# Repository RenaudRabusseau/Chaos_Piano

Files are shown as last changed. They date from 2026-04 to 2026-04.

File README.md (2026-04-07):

# Chaos Piano

An interactive sound and light installation that transforms visitor proximity into coordinated chaos. Built around a decommissioned upright piano for the Fondation du Doute (Blois, France).

As a visitor approaches, the system responds with increasing intensity: vibrating motors excite the piano frame, LED strips strobe with random independent dropouts, a synthesized drone grows louder and more distorted, live microphones capture ambient sound and feed it through reverb and delay, and an ambient track swells through a separate speaker pair.

---

## How It Works

The system is split across two RP2040-Zero microcontrollers connected via I2C. Brain 1 handles the physical world (sensing and actuation), Brain 2 handles audio (synthesis, live processing, and playback). Two separate 12V power supplies isolate the noisy actuation domain from the audio amplifiers.

Four ultrasonic sensors detect visitor proximity and map the closest distance to a single byte (0 = nobody, 255 = very close). This byte drives everything: drone volume and distortion, LED strobe speed, motor outburst frequency, mic processing intensity, and ambient track volume.

### Signal Flow

```
Visitor proximity
    │
    ├──► Brain 1 (RP2040-Zero, dual-core)
    │       Core 0: 4x HC-SR04 sensors → proximity byte → I2C to Brain 2
    │       Core 1: 3x LED strobes with random dropouts
    │                3x motor outbursts (one at a time, spatialized)
    │
    └──► Brain 2 (RP2040-Zero, single-core)
            Drone: sine → distortion → bitcrush → flanger → autopan → I2S DAC
            Mics:  2x MAX9814 → noise gate → reverb → delay → I2S DAC
            Ambient: DFPlayer Mini → separate amp → speakers 3+4
```

### Schematic

[View KiCad schematic (PDF)](KICAD/chaos_piano/chaos_piano.pdf)

---

## Hardware

| Component | Qty | Role |
|---|-----|---|
| RP2040-Zero (Waveshare) | 2 | Brain 1 (controller), Brain 2 (audio) |
| HC-SR04 ultrasonic sensor | 4 | Proximity detection |
| MAX9814 preamp module | 2 | Condenser mic input (40dB, fast AGC) |
| PCM5102 I2S DAC | 1 | Digital audio output |
| PAM8610 amplifier | 2 | Speaker drivers (separate PSU from actuation) |
| Speakers (4 ohm 10W) | 4 | 2 for live audio, 2 for ambient track |
| DFPlayer Mini | 1 | Ambient MP3 playback |
| IRLZ44N N-MOSFET | 6 | 12V switching (3 motors, 3 LED strips) |
| Vibrating motor | 3 | Tactile/acoustic excitation |
| 12V RGB LED strip | 3 | Visual feedback (white strobe) |
| 12V PSU | 2 | #1 brains + actuation, #2 audio amplifiers |
| 5V step-down converter | 1 | Powers sensors and DFPlayer from PSU #1 |

### Custom Boards

Three perfboards built by hand with screw terminals for field serviceability:

**MOSFET board:** 6x IRLZ44N with 10k pull-downs and flyback diodes, 12V/GND rails.
**Voltage divider board:** 4x dividers (1k/2k) converting 5V HC-SR04 echo signals to 3.3V.
**I2C board:** 2x 4.7k pull-ups, 4 screw terminals (SDA, SCL, 3.3V, GND).

### Power Architecture

Two separate 12V supplies eliminate ground-coupled PWM noise from the audio path:

- **PSU #1:** MOSFET board, 5V step-down (sensors, DFPlayer), brains (via USB for desk prototype)
- **PSU #2:** Both PAM8610 amplifiers only

---

## Audio DSP Chain

Brain 2 runs a real-time audio engine at 44100Hz, synchronized to DMA-based ADC sampling.

**Drone path (synthesized):** Phase-accumulator sine oscillator (440Hz) through proximity-scaled distortion (up to 8x gain, hard clip), bitcrusher (up to 12 bits removed), flanger (1024-sample buffer, triangle LFO), proximity volume, and stereo autopanner.

**Mic path (live input):** Two MAX9814 condenser mics sampled via round-robin ADC at 22050Hz each, mono downmixed, through asymmetric noise gate, Schroeder reverb (4 comb filters), and 600ms delay with feedback.

**Ambient path (separate analog):** DFPlayer Mini decodes MP3 from SD card, analog output to PAM8610 #2 through its own DAC. Volume controlled by Brain 2 via 9600 baud UART.

---

## Actuation Behavior

**LEDs:** Unified strobe rate scales with proximity. Each strip independently drops out (goes dark) for random durations. Dropout probability increases with proximity, creating visual chaos.

**Motors:** Gentle baseline hum scales with proximity. Individual motors fire random outbursts (one at a time, never simultaneous) with randomly chosen sharp or faded attacks. Outburst frequency, intensity, and duration increase with proximity, spatializing tactile chaos across three positions.

---

## Build and Upload

Requires [PlatformIO](https://platformio.org/).

```bash
# Build both brains
pio run

# Upload Brain 1 (blue heartbeat LED)
pio run -e brain1_controller -t upload

# Upload Brain 2 (green triple-flash LED)
pio run -e brain2_audio -t upload

# Monitor Brain 1
pio device monitor -p /dev/serial/by-id/usb-Waveshare_RP2040_Zero_E66428C51F4BB630-if00 -b 115200

# Monitor Brain 2
pio device monitor -p /dev/serial/by-id/usb-Waveshare_RP2040_Zero_E66428C51F63B530-if00 -b 115200
```

---

## Repository Structure

```
Chaos_Piano/
├── README.md                        # This file
├── ARCHITECTURE.md                  # Complete technical reference
├── platformio.ini                   # Build config: two environments
├── KICAD/
│   └── chaos_piano/
│       ├── chaos_piano.kicad_sch    # Schematic
│       ├── chaos_piano.kicad_pcb    # PCB layout
│       └── chaos_piano.pdf          # Schematic export
├── lib/
│   └── shared_protocol/
│       ├── chaos_protocol.h         # Pin assignments, I2C protocol, message format
│       └── library.json             # PlatformIO library metadata
└── src/
    ├── brain1_controller/
    │   └── main.cpp                 # Core 0: sensors + I2C. Core 1: chaotic LEDs + motors.
    └── brain2_audio/
        └── main.cpp                 # Audio engine: drone DSP + dual mic + DFPlayer
```

See [ARCHITECTURE.md](ARCHITECTURE.md) for the complete technical reference including pin maps, wiring diagrams, communication protocol, and all tuning parameters.

---

## Academic Context

Developed as a portfolio project for a BTS CIEL (Cybersecurity, IT and Electronics) program. Demonstrates practical competency across embedded systems, real-time signal processing, and human-machine interaction:

- Dual-microcontroller architecture with I2C inter-processor communication
- Real-time DSP on a 133MHz ARM Cortex-M0+ (no FPU, no RTOS)
- DMA-driven ADC for jitter-free audio sampling
- Power domain isolation for EMI management
- Custom perfboard design and hand assembly
- Proximity-driven state machine with randomized actuation behavior

---

## Author

**Renaud Rabusseau** - Electronics engineering student, former technical translator and conference interpreter. This project bridges 15 years of professional audio experience with embedded systems engineering.

---

## License

This project is open source. See individual files for details.

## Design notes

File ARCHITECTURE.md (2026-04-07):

# Chaos Piano — Architecture Reference

**Version:** April 2026 desk prototype (final working build)
**Target:** La Fondation du Doute, Blois, France — May 2026
**Author:** Renaud

---

## Concept

Interactive sound installation where human proximity controls audio effects,
lighting, and physical actuators. The closer a visitor gets, the more chaotic
the piano becomes: the drone grows louder and more distorted, LED strips strobe
faster with random independent dropouts, motors fire random independent
outbursts, and the ambient track swells.

---

## System Overview

```
  ┌──────────────────────┐          ┌──────────────────────┐
  │    12V PSU #1         │          │    12V PSU #2         │
  │  (brains + actuation) │          │  (audio amplifiers)   │
  └──┬────────┬───────────┘          └──┬────────┬──────────┘
     │        │                         │        │
  ┌──▼──┐  ┌──▼──┐                   ┌──▼──┐  ┌──▼──┐
  │Motor│  │ LED │                   │PAM  │  │PAM  │
  │MOSFET│ │MOSFET│                  │8610 │  │8610 │
  │board │ │board │                  │ #1  │  │ #2  │
  └──▲──┘  └──▲──┘                   └──▲──┘  └──▲──┘
     │        │                         │        │
     │        │     ┌───────────────────┘        │
     │        │     │    ┌──────────────────────-┘
     │        │     │    │
  ┌──┴────────┴─────┴────┴─────────────────────────────────┐
  │                                                        │
  │  ┌──────────────┐    I2C     ┌──────────────────────┐  │
  │  │   BRAIN 1    │◄──────────►│      BRAIN 2         │  │
  │  │  Controller  │  (4 bytes  │    Audio Engine      │  │
  │  │  RP2040-Zero │  @ 20Hz)   │    RP2040-Zero       │  │
  │  └──────┬───────┘            └──┬────┬────┬─────────┘  │
  │         │                       │    │    │            │
  │    ┌────▼────┐             ┌────▼┐ ┌─▼──┐ ┌▼────────┐  │
  │    │ HC-SR04 │             │MAX  │ │I2S │ │DFPlayer │  │
  │    │  ×4     │             │9814 │ │DAC │ │Mini     │  │
  │    └─────────┘             │ ×2  │ │PCM │ │(ambient)│  │
  │                            └─────┘ │5102│ └─────────┘  │
  │                                    └────┘              │
  └────────────────────────────────────────────────────────┘
```

---

## Power Architecture

The system uses two separate 12V power supplies to eliminate ground-coupled
PWM switching noise from the audio path. This was the key fix for audible
LED/motor buzz in the speakers.

| PSU | Voltage | Min Current | Powers |
|-----|---|---|---|
| PSU #1 | 12V | 2A+ | MOSFET board (motors, LEDs), 5V step-down (sensors, DFPlayer), brains (via USB) |
| PSU #2 | 12V | 2A+ | PAM8610 #1 (live audio), PAM8610 #2 (ambient audio) |

The two PSUs share no ground connection. The brains are powered via USB
from a computer (desk prototype) or from PSU #1's 5V step-down (exhibit mode).
The 5V step-down converts PSU #1's 12V to 5V for the HC-SR04 sensors and
the DFPlayer Mini.

---

## Components

| Component | Qty | Role | Voltage | Notes |
|---|-----|---|---|---|
| RP2040-Zero (Waveshare) | 2 | Brain 1 (controller), Brain 2 (audio) | 3.3V (USB-C 5V) | Orange tape = Brain 1, new board = Brain 2 |
| HC-SR04 ultrasonic sensor | 4 | Distance detection | 5V | ECHO needs voltage divider (1kΩ + 2kΩ) |
| MAX9814 preamp module | 2 | Condenser mic input | 3.3V | GAIN → 3.3V = 40dB, AR → 3.3V = fast release |
| PCM5102 I2S DAC | 1 | Digital-to-analog audio output | 3.3V | SCK pin → GND (internal clock mode) |
| PAM8610 amplifier | 2 | Speaker driver | 12V (PSU #2) | #1 for live audio, #2 for DFPlayer ambient |
| Speakers (4Ω 10W) | 4 | Sound output | — | 2 per PAM8610 (stereo) |
| DFPlayer Mini | 1 | Ambient track playback | 5V | 4GB MicroSD with 001.mp3 in root |
| IRLZ44N N-MOSFET (TO-220) | 6 | 12V switching for motors/LEDs | — | Logic-level: fully on at 3.3V gate |
| Vibrating motor | 3 | Tactile feedback | 12V | Flyback diode (1N4007) required |
| 12V LED strip (RGB) | 3 | Visual feedback (white strobe) | 12V | All 3 color wires joined → single MOSFET |
| 12V PSU | 2 | Power | 12V | #1 for brains+actuation, #2 for amps |
| 5V step-down converter | 1 | 12V → 5V for sensors + DFPlayer | 5V | Connected to PSU #1 |
| 1kΩ resistor | 5 | 4× voltage divider top + 1× DFPlayer TX | — | |
| 2kΩ resistor | 4 | HC-SR04 voltage divider (bottom) | — | One per echo line |
| 4.7kΩ resistor | 2 | I2C pull-ups (SDA + SCL) | — | To 3.3V, mounted on I2C board |
| 10kΩ resistor | 6 | MOSFET gate pull-downs | — | One per MOSFET: gate → source |
| 1N4007 diode | 3 | Motor flyback protection | — | Cathode (stripe) → motor +, anode → motor − |
| 4GB MicroSD card | 1 | DFPlayer audio storage | — | FAT32, file: /001.mp3 |

---

## Custom Boards

### MOSFET Board
Perfboard with 6× IRLZ44N MOSFETs (3 for LEDs, 3 for motors), 6× 10kΩ
gate pull-down resistors, 3× 1N4007 flyback diodes (motor MOSFETs only),
12V and GND power rails. Screw terminals for load connections.

### Voltage Divider Board
Perfboard with 4× voltage dividers (1kΩ top + 2kΩ bottom) for the HC-SR04
echo lines. Converts 5V echo signals to ~3.3V safe for RP2040 GPIO inputs.
DuPont connectors on the Brain 1 side, open leads to Wago connectors on
the sensor side.

### I2C Board
Small perfboard with 4 screw terminals (SDA, SCL, 3.3V, GND) and 2× 4.7kΩ
pull-up resistors (SDA→3.3V, SCL→3.3V). Both brains connect their I2C lines
here. 3.3V sourced from one brain's 3V3 pin.

---

## Boards

### Brain 1 — Physical Controller

- **Board:** RP2040-Zero (Waveshare), orange tape
- **Serial:** `E66428C51F4BB630`
- **USB port:** `/dev/serial/by-id/usb-Waveshare_RP2040_Zero_E66428C51F4BB630-if00`
- **PlatformIO env:** `brain1_controller`
- **NeoPixel:** Blue heartbeat (1s on, 1s off)
- **Role:** Reads 4 ultrasonic sensors, computes proximity, sends I2C to Brain 2, drives chaotic motor outbursts and LED strobes with random dropouts
- **Architecture:** Dual-core. Core 0 = sensors + I2C. Core 1 = LED strobe + motor chaos.

### Brain 2 — Audio Engine

- **Board:** RP2040-Zero (Waveshare), no tape
- **Serial:** `E66428C51F63B530`
- **USB port:** `/dev/serial/by-id/usb-Waveshare_RP2040_Zero_E66428C51F63B530-if00`
- **PlatformIO env:** `brain2_audio`
- **NeoPixel:** Green triple-flash (3 blinks, 1.5s cycle)
- **Role:** Receives proximity via I2C, generates drone with DSP effects, processes dual live mics, controls DFPlayer ambient track
- **Architecture:** Single-core. Audio processing synchronized to ADCInput DMA at 44100Hz.

---

## Pin Map

### Brain 1

| GPIO | Function | Direction | Notes |
|---|---|---|---|
| 0 | LED strip 0 MOSFET gate | OUT | 10kΩ pull-down to GND |
| 1 | LED strip 1 MOSFET gate | OUT | 10kΩ pull-down to GND |
| 2 | LED strip 2 MOSFET gate | OUT | 10kΩ pull-down to GND |
| 3 | *free* | — | Available on edge header |
| 4 | I2C SDA | I/O | 4.7kΩ pull-up to 3.3V (on I2C board) |
| 5 | I2C SCL | I/O | 4.7kΩ pull-up to 3.3V (on I2C board) |
| 6 | Ultrasonic TRIGGER (shared) | OUT | All 4 sensors share this pin |
| 7 | Ultrasonic ECHO 0 | IN | 1kΩ + 2kΩ voltage divider from 5V |
| 8 | Ultrasonic ECHO 1 | IN | 1kΩ + 2kΩ voltage divider from 5V |
| 9 | Ultrasonic ECHO 2 | IN | 1kΩ + 2kΩ voltage divider from 5V |
| 10 | Ultrasonic ECHO 3 | IN | 1kΩ + 2kΩ voltage divider from 5V |
| 11 | Motor 0 MOSFET gate | OUT | 10kΩ pull-down, flyback diode on motor |
| 12 | Motor 1 MOSFET gate | OUT | 10kΩ pull-down, flyback diode on motor |
| 13 | Motor 2 MOSFET gate | OUT | 10kΩ pull-down, flyback diode on motor |
| 14 | *free* | — | Available on edge header |
| 15 | *free* | — | Available on edge header |
| 16 | Onboard NeoPixel (WS2812) | OUT | Hardwired — cannot be reassigned |

### Brain 2

| GPIO | Function | Direction | Notes |
|---|---|---|---|
| 0 | DFPlayer TX | OUT | 1kΩ resistor to DFPlayer RX |
| 1 | DFPlayer RX | IN | Direct connection |
| 2 | *free* | — | |
| 3 | *free* | — | |
| 4 | I2C SDA | I/O | 4.7kΩ pull-up to 3.3V (on I2C board) |
| 5 | I2C SCL | I/O | 4.7kΩ pull-up to 3.3V (on I2C board) |
| 6 | I2S BCK (bit clock) | OUT | To PCM5102 BCK |
| 7 | I2S LRCK (word select) | OUT | To PCM5102 LCK (auto = BCK+1) |
| 8 | I2S DOUT (data) | OUT | To PCM5102 DIN |
| 9-15 | *free* | — | |
| 16 | Onboard NeoPixel (WS2812) | OUT | Hardwired |
| 26 | MAX9814 mic 0 (ADC0) | IN | Analog input |
| 27 | MAX9814 mic 1 (ADC1) | IN | Analog input |
| 28 | *free* (ADC2) | IN | |

---

## Wiring Reference

### I2C Bus (via I2C board)

```
Brain 1 GPIO4 (SDA) ──┐
                       ├── I2C Board SDA terminal ── 4.7kΩ ── 3.3V
Brain 2 GPIO4 (SDA) ──┘

Brain 1 GPIO5 (SCL) ──┐
                       ├── I2C Board SCL terminal ── 4.7kΩ ── 3.3V
Brain 2 GPIO5 (SCL) ──┘

Either brain GND ──── I2C Board GND terminal
Either brain 3V3 ──── I2C Board 3.3V terminal
```

### HC-SR04 Ultrasonic Sensor (×4, example for sensor 0)

```
5V (step-down) ──── HC-SR04 VCC
GND            ──── HC-SR04 GND
Brain 1 GPIO6  ──── HC-SR04 TRIG  (shared by all 4 sensors via Wago)

HC-SR04 ECHO ──── 1kΩ ──┬──── Brain 1 GPIO7
                         │
                        2kΩ
                         │
                        GND
```
The 1kΩ + 2kΩ voltage divider converts the HC-SR04's 5V echo signal to
~3.3V for the RP2040's GPIO input. Without this, the 5V would damage the chip.

### Motor Circuit (×3, example for motor 0)

```
12V PSU #1 (+) ──── Motor (+)
                    Motor (−) ──── IRLZ44N Drain (center pin)
                                    IRLZ44N Source (right pin) ──── GND
                                    IRLZ44N Gate (left pin) ──── Brain 1 GPIO11
                                             │
                                            10kΩ
                                             │
                                            GND

Flyback diode across motor:
  Cathode (stripe) → Motor (+)
  Anode → Motor (−)
```

### LED Strip Circuit (×3, example for strip 0)

```
12V PSU #1 (+) ──── LED strip (+12V)
LED strip R (−) ─┐
LED strip G (−) ──┤──── IRLZ44N Drain (center pin)
LED strip B (−) ─┘      IRLZ44N Source (right pin) ──── GND
                          IRLZ44N Gate (left pin) ──── Brain 1 GPIO0
                                   │
                                  10kΩ
                                   │
                                  GND
```
All 3 color wires joined together = white when ON. Single MOSFET controls brightness.

### PCM5102 DAC

```
Brain 2 GPIO6 ──── BCK
Brain 2 GPIO7 ──── LCK
Brain 2 GPIO8 ──── DIN
3.3V          ──── VIN
GND           ──── GND
GND           ──── SCK  (ties internal clock mode)

PCM5102 3.5mm out ──── PAM8610 #1 audio input
```

### DFPlayer Mini

```
Brain 2 GPIO0 ──── 1kΩ ──── DFPlayer RX
Brain 2 GPIO1 ──────────── DFPlayer TX
5V (step-down) ─────────── DFPlayer VCC
GND           ──────────── DFPlayer GND
DFPlayer DAC_L ──── PAM8610 #2 Left input
DFPlayer DAC_R ──── PAM8610 #2 Right input
```

### MAX9814 Microphone (×2)

```
Mic 0:
  3.3V ──── MAX9814 VDD
  GND  ──── MAX9814 GND
  3.3V ──── MAX9814 GAIN  (40dB gain setting)
  3.3V ──── MAX9814 AR    (fastest AGC release = 1:500)
  MAX9814 OUT ──── Brain 2 GPIO26 (ADC0)

Mic 1:
  3.3V ──── MAX9814 VDD
  GND  ──── MAX9814 GND
  3.3V ──── MAX9814 GAIN  (40dB gain setting)
  3.3V ──── MAX9814 AR    (fastest AGC release = 1:500)
  MAX9814 OUT ──── Brain 2 GPIO27 (ADC1)
```

### PAM8610 Amplifiers

```
PAM8610 #1 (live audio):
  12V PSU #2 ──── Power in
  GND PSU #2 ──── GND
  PCM5102 3.5mm ──── Audio input
  Speakers 1+2 ──── Output L/R

PAM8610 #2 (ambient):
  12V PSU #2 ──── Power in
  GND PSU #2 ──── GND
  DFPlayer DAC_L/R ──── Audio input L/R
  Speakers 3+4 ──── Output L/R
```

---

## Communication Protocol

### I2C (Brain 1 → Brain 2)

- **Address:** 0x42
- **Speed:** 100kHz
- **Rate:** 20Hz (every 50ms)
- **Message:** 4 bytes, packed struct:

| Byte | Field | Description |
|---|---|---|
| 0 | header | Magic byte 0xC0 |
| 1 | proximity | 0=nobody, 255=very close |
| 2 | sensor_count | Valid sensors this sweep (0-4) |
| 3 | checksum | XOR of bytes 0-2 |

### DFPlayer Serial (Brain 2 → DFPlayer)

- **UART:** Serial1 at 9600 baud
- **Protocol:** 10-byte frames (0x7E start, 0xEF end, checksum)
- **Commands used:** 0x06 (set volume), 0x08 (loop track)
- **Rate limit:** Max 1 command per 200ms

---

## Audio Signal Chain

```
DRONE PATH:
  fastSine(440Hz)
    → >>DRONE_PRE_SHIFT (headroom)
    → Distortion (gain 1x-8x, hard clip)
    → Bitcrusher (0-12 bits removed)
    → Flanger (1024-sample buffer, triangle LFO)
    → Proximity Volume (DRONE_VOLUME_MIN → DRONE_VOLUME_MAX)
    → Autopan (triangle LFO, speed+depth scale with proximity)
    → stereo L/R

MIC PATH (dual mic, interleaved ADC):
  MAX9814 ×2 (40dB, ADC via DMA at 44100Hz, round-robin → 22050Hz each)
    → DC bias removal (subtract MIC_BIAS)
    → Mono downmix (average of both mics)
    → Noise Gate (asymmetric envelope, threshold-based mute)
    → MIC_VOLUME scaling
    → Reverb (4 comb filters, Schroeder design)
    → Delay (circular buffer, 600ms, feedback)
    → mono (centered in both channels)

FINAL MIX:
  droneLeft + mic → clip → I2S left
  droneRight + mic → clip → I2S right
    → PCM5102 DAC → 3.5mm → PAM8610 #1 (PSU #2) → Speakers 1+2

DFPLAYER PATH (separate analog):
  SD card → DFPlayer decoder → DAC_L/DAC_R → PAM8610 #2 (PSU #2) → Speakers 3+4
  Volume controlled by Brain 2 UART commands (proximity-scaled)
```

---

## Actuation Behavior

### LED Strips (Core 1, Brain 1)

**Idle (prox < LED_PROX_THRESHOLD):** All three strips pulse together in a
slow dim/bright cycle, making the installation look alive even when nobody
is nearby.

**Active (prox >= threshold):** All three strips strobe at the same rate,
which increases with proximity. On top of the shared strobe, each strip
independently and randomly "drops out" (goes dark) for a short random
duration. Dropout probability and duration scale with proximity: at low
proximity the strobe is uniform, at high proximity the three strips blink
in and out chaotically.

### Motors (Core 1, Brain 1)

**Idle (prox = 0):** All motors off.

**Active (prox > 0):** All three motors run at a gentle baseline PWM that
scales with proximity. On top of this baseline, individual motors randomly
fire outbursts: short bursts to higher intensity, one motor at a time (never
simultaneous). Each burst randomly uses either a sharp snap or a smooth fade
for its attack. The return to baseline always fades smoothly. Outburst
frequency, intensity, and duration all increase with proximity, creating
spatialized tactile chaos across the three motor positions.

---

## Build Commands

```bash
# Build both brains
pio run

# Upload Brain 1 only
pio run -e brain1_controller -t upload

# Upload Brain 2 only
pio run -e brain2_audio -t upload

# Monitor Brain 1 (blue heartbeat)
pio device monitor -p /dev/serial/by-id/usb-Waveshare_RP2040_Zero_E66428C51F4BB630-if00 -b 115200

# Monitor Brain 2 (green triple-flash)
pio device monitor -p /dev/serial/by-id/usb-Waveshare_RP2040_Zero_E66428C51F63B530-if00 -b 115200

# Monitor both simultaneously (interleaved output)
pio device monitor -p /dev/serial/by-id/usb-Waveshare_RP2040_Zero_E66428C51F4BB630-if00 -b 115200 &
pio device monitor -p /dev/serial/by-id/usb-Waveshare_RP2040_Zero_E66428C51F63B530-if00 -b 115200
```

---

## Tuning Parameters Quick Reference

### Brain 1 (src/brain1_controller/main.cpp)

| Parameter | Default | Range | Effect |
|---|---|---|---|
| DETECT_MIN_CM | 1 | 1-50 | Closest detection distance |
| DETECT_MAX_CM | 75 | 50-400 | Farthest detection distance |
| MOTOR_BASELINE_MIN | 0 | 0-50 | Motor baseline PWM at prox=0 |
| MOTOR_BASELINE_MAX | 40 | 10-100 | Motor baseline PWM at max proximity |
| MOTOR_BURST_MIN | 80 | 40-150 | Minimum burst intensity |
| MOTOR_BURST_MAX | 180 | 100-255 | Maximum burst intensity |
| MOTOR_BURST_DUR_MIN | 50 | 20-200 | Shortest burst (ms) |
| MOTOR_BURST_DUR_MAX | 400 | 100-1000 | Longest burst (ms) |
| MOTOR_PAUSE_MIN | 200 | 50-500 | Shortest gap between bursts (ms) |
| MOTOR_PAUSE_MAX | 2000 | 500-5000 | Longest gap between bursts (ms) |
| MOTOR_FADE_SPEED | 8 | 1-32 | PWM change per loop iteration (higher=faster) |
| LED_IDLE_BRIGHT | 15 | 0-255 | Idle blink ON brightness |
| LED_IDLE_DIM | 5 | 0-255 | Idle blink OFF brightness |
| LED_IDLE_PERIOD_MS | 1000 | 200-5000 | Idle blink half-period (ms) |
| LED_STROBE_BRIGHT_MIN | 30 | 0-255 | Active strobe dim brightness |
| LED_STROBE_BRIGHT_MAX | 255 | 0-255 | Active strobe full brightness |
| LED_STROBE_SLOW_US | 500000 | 100000-2000000 | Slowest strobe (us) |
| LED_STROBE_FAST_US | 2000 | 500-50000 | Fastest strobe (us) |
| LED_PROX_THRESHOLD | 5 | 1-50 | Proximity to exit idle mode |
| LED_DROPOUT_DUR_MIN | 30 | 10-200 | Shortest LED dropout (ms) |
| LED_DROPOUT_DUR_MAX | 300 | 50-1000 | Longest LED dropout (ms) |
| LED_DROPOUT_CHANCE_MIN | 0 | 0-20 | Dropout probability at low prox (0-255 scale) |
| LED_DROPOUT_CHANCE_MAX | 40 | 10-100 | Dropout probability at max prox (0-255 scale) |
| SENSOR_ZERO_MAX | 10 | 3-30 | Consecutive 0s before release |

### Brain 2 (src/brain2_audio/main.cpp)

| Parameter | Default | Range | Effect |
|---|---|---|---|
| MIC_BIAS | 1540 | 1400-1700 | MAX9814 DC offset (calibrate!) |
| MIC_VOLUME | 255 | 0-255 | Mic loudness (128=unity, 255=2x boost) |
| GATE_THRESHOLD | 200 | 50-5000 | Noise gate sensitivity |
| GATE_ATTACK | 0.5 | 0.01-1.0 | Gate open speed |
| GATE_RELEASE | 0.1 | 0.001-0.5 | Gate close speed |
| REVERB_DECAY | 215 | 150-225 | Reverb tail length |
| REVERB_WET | 200 | 0-255 | Reverb wet/dry mix |
| DELAY_TIME_MS | 600 | 100-800 | Echo time in ms |
| DELAY_FEEDBACK | 100 | 0-200 | Echo repeats (200+=danger) |
| DELAY_MIX | 140 | 0-255 | Echo volume |
| DRONE_FREQ_HZ | 440 | 50-2000 | Drone pitch in Hz |
| DRONE_PRE_SHIFT | 2 | 1-4 | Headroom (higher=quieter input to FX) |
| DRONE_VOLUME_MIN | 120 | 0-255 | Drone volume at idle |
| DRONE_VOLUME_MAX | 255 | 0-255 | Drone volume at closest |
| DIST_GAIN_MULTIPLIER | 7 | 1-15 | Distortion max gain factor |
| BITCRUSH_MAX_BITS | 12 | 1-14 | Max bit reduction |
| FLANGER_LFO_SPEED | 97391 | 10000-500000 | Flanger sweep rate |
| PAN_SPEED_MIN | 15000 | 1000-100000 | Slowest autopan |
| PAN_SPEED_MAX | 300000 | 100000-1000000 | Fastest autopan |
| PAN_DEPTH_MIN | 0 | 0-128 | Pan width when idle |
| PAN_DEPTH_MAX | 200 | 0-255 | Pan width at closest |
| DFPLAYER_VOL_MIN | 15 | 0-30 | Ambient volume idle |
| DFPLAYER_VOL_MAX | 30 | 0-30 | Ambient volume closest |
| DFPLAYER_TRACK | 1 | 1-99 | Track number to loop |
| GLITCH_CHANCE_MIN | 0 | 0-50 | Glitch probability idle |
| GLITCH_CHANCE_MAX | 0 | 0-255 | Glitch probability closest (0=off) |
| GLITCH_MIN_LENGTH | 2000 | 441-22050 | Shortest glitch (samples) |
| GLITCH_MAX_LENGTH | 10000 | 2000-44100 | Longest glitch (samples) |
| GLITCH_FADE_SPEED | 4 | 1-16 | Glitch fade smoothness |

---

## Project Structure

```
chaos-piano/
├── platformio.ini                   # Build config: two environments
├── lib/
│   └── shared_protocol/
│       ├── chaos_protocol.h         # SINGLE SOURCE OF TRUTH: pins, I2C, message format
│       └── library.json             # PlatformIO library metadata
├── src/
│   ├── brain1_controller/
│   │   └── main.cpp                 # Core 0: sensors + I2C. Core 1: chaotic LEDs + motors.
│   └── brain2_audio/
│       └── main.cpp                 # Audio engine: drone DSP + dual mic + DFPlayer
└── ARCHITECTURE.md                  # This file
```

---

## Resolved Issues

- **EMI from MOSFET PWM switching:** 12V PWM switching on the MOSFET board
  coupled ground noise into both audio amplifiers (audible as a buzz/whine
  synchronized with LED blink rate). **Fixed** by using a separate 12V PSU
  for the two PAM8610 amplifiers, completely isolating the audio ground
  from the actuation ground.

- **Floating ADC inputs:** Before the MAX9814 mics were connected, the ADC
  inputs on GPIO26/27 floated at ~2950, causing the noise gate to stay
  permanently open. **Fixed** by connecting both mics (the MAX9814 output
  provides a stable DC bias around 1540).

- **Dead PCM5102 module:** During a rebuild, the PCM5102 DAC's LCK input
  was damaged (pulling the line from 1.6V to 0.5V). **Fixed** by replacing
  the module. Lesson: handle these boards carefully and avoid shorts during
  rewiring.

## Known Limitations

- **Feedback loop:** MAX9814 AGC boosts quiet feedback from speakers. Managed
  by tuning GATE_THRESHOLD, MIC_VOLUME, REVERB_WET, and DELAY_FEEDBACK.
  Physical separation of mic and speakers remains important for the final build.

- **DFPlayer glitch sync:** DFPlayer mute commands have ~30-50ms latency
  (serial processing). Glitch cuts won't be perfectly synchronized with live
  audio. (Glitch system currently disabled: GLITCH_CHANCE_MAX = 0.)

- **Standalone boot:** Uses `delay(2000)` instead of `while(!Serial)`. Works
  for exhibit mode (no computer needed) but serial output may be missed if
  monitor isn't open within 2 seconds of boot.

- **Dual mic sample rate:** With two mics sharing one ADC via round-robin,
  each mic is sampled at 22050Hz (half the 44100Hz ADC clock). Adequate for
  voice and claps but limits high-frequency capture above ~10kHz.

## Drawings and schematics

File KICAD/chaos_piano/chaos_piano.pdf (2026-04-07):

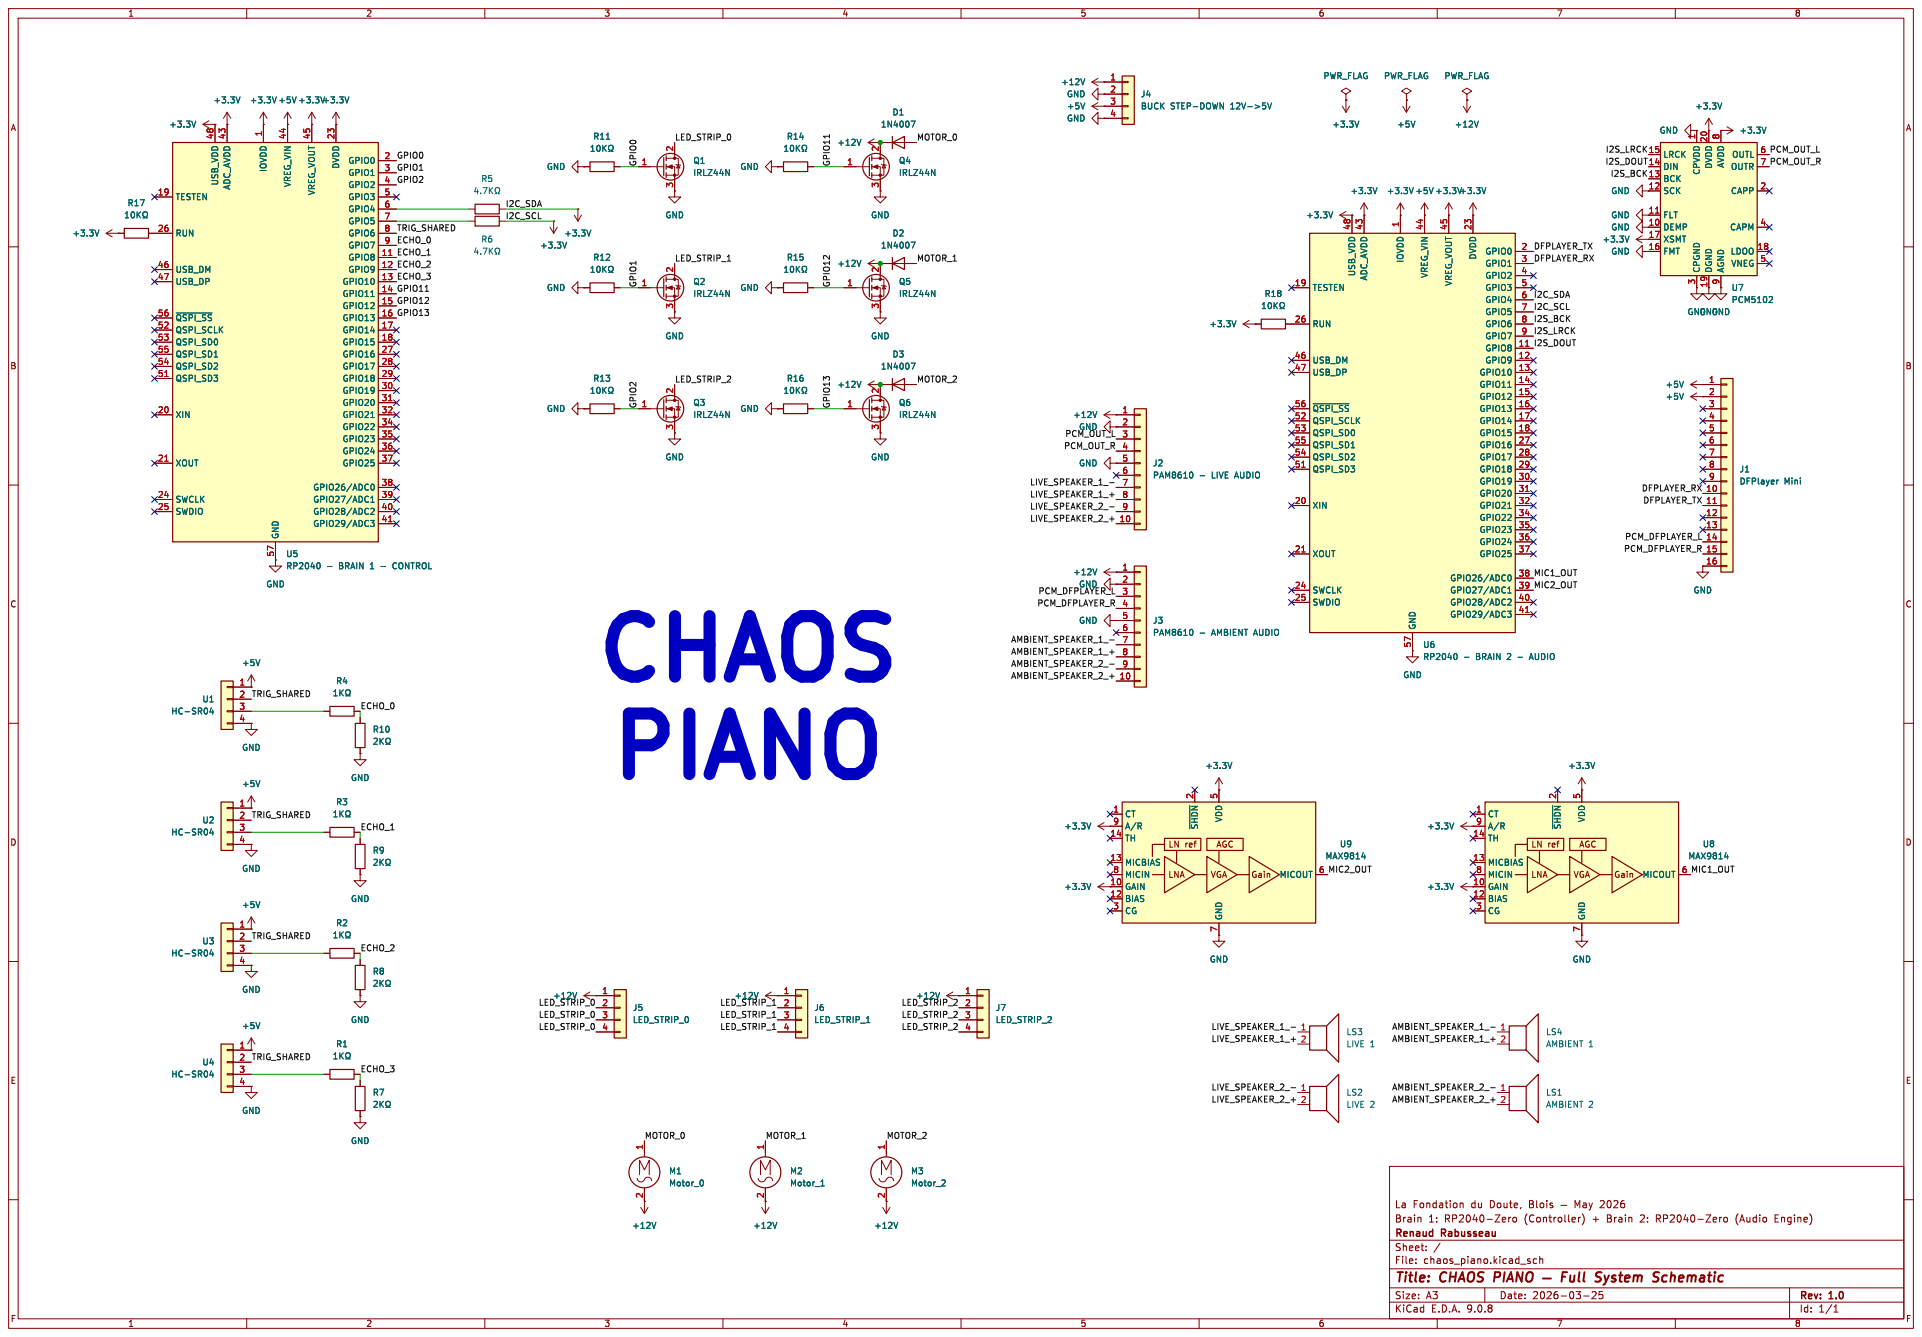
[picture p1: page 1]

1 GND 57 VREG_VIN 44 VREG_VOUT 45 DVDD 23 GPIO0 2 GPIO1 3 GPIO2 4 GPIO3 5 GPIO4 6 GPIO5 7 GPIO6 8 GPIO7 9 GPIO8 11 GPIO9 12 GPIO10 13 GPIO11 14 GPIO12 15 GPIO13 16 GPIO14 17 GPIO15 18 GPIO16 27 GPIO17 28 GPIO18 29 GPIO19 30 GPIO20 31 GPIO21 32 GPIO22 34 GPIO23 35 GPIO24 36 GPIO25 37 GPIO26/ADC0 38 GPIO27/ADC1 39 GPIO28/ADC2 40 GPIO29/ADC3 41 U5 RP2040 - BRAIN 1 - CONTROL

1 GND 57 VREG_VIN 44 VREG_VOUT 45 DVDD 23 GPIO0 2 GPIO1 3 GPIO2 4 GPIO3 5 GPIO4 6 GPIO5 7 GPIO6 8 GPIO7 9 GPIO8 11 GPIO9 12 GPIO10 13 GPIO11 14 GPIO12 15 GPIO13 16 GPIO14 17 GPIO15 18 GPIO16 27 GPIO17 28 GPIO18 29 GPIO19 30 GPIO20 31 GPIO21 32 GPIO22 34 GPIO23 35 GPIO24 36 GPIO25 37 GPIO26/ADC0 38 GPIO27/ADC1 39 GPIO28/ADC2 40 GPIO29/ADC3 41 U6 RP2040 - BRAIN 2 - AUDIO

Id: 1/1 Title: CHAOS PIANO þÿ Full System Schematic

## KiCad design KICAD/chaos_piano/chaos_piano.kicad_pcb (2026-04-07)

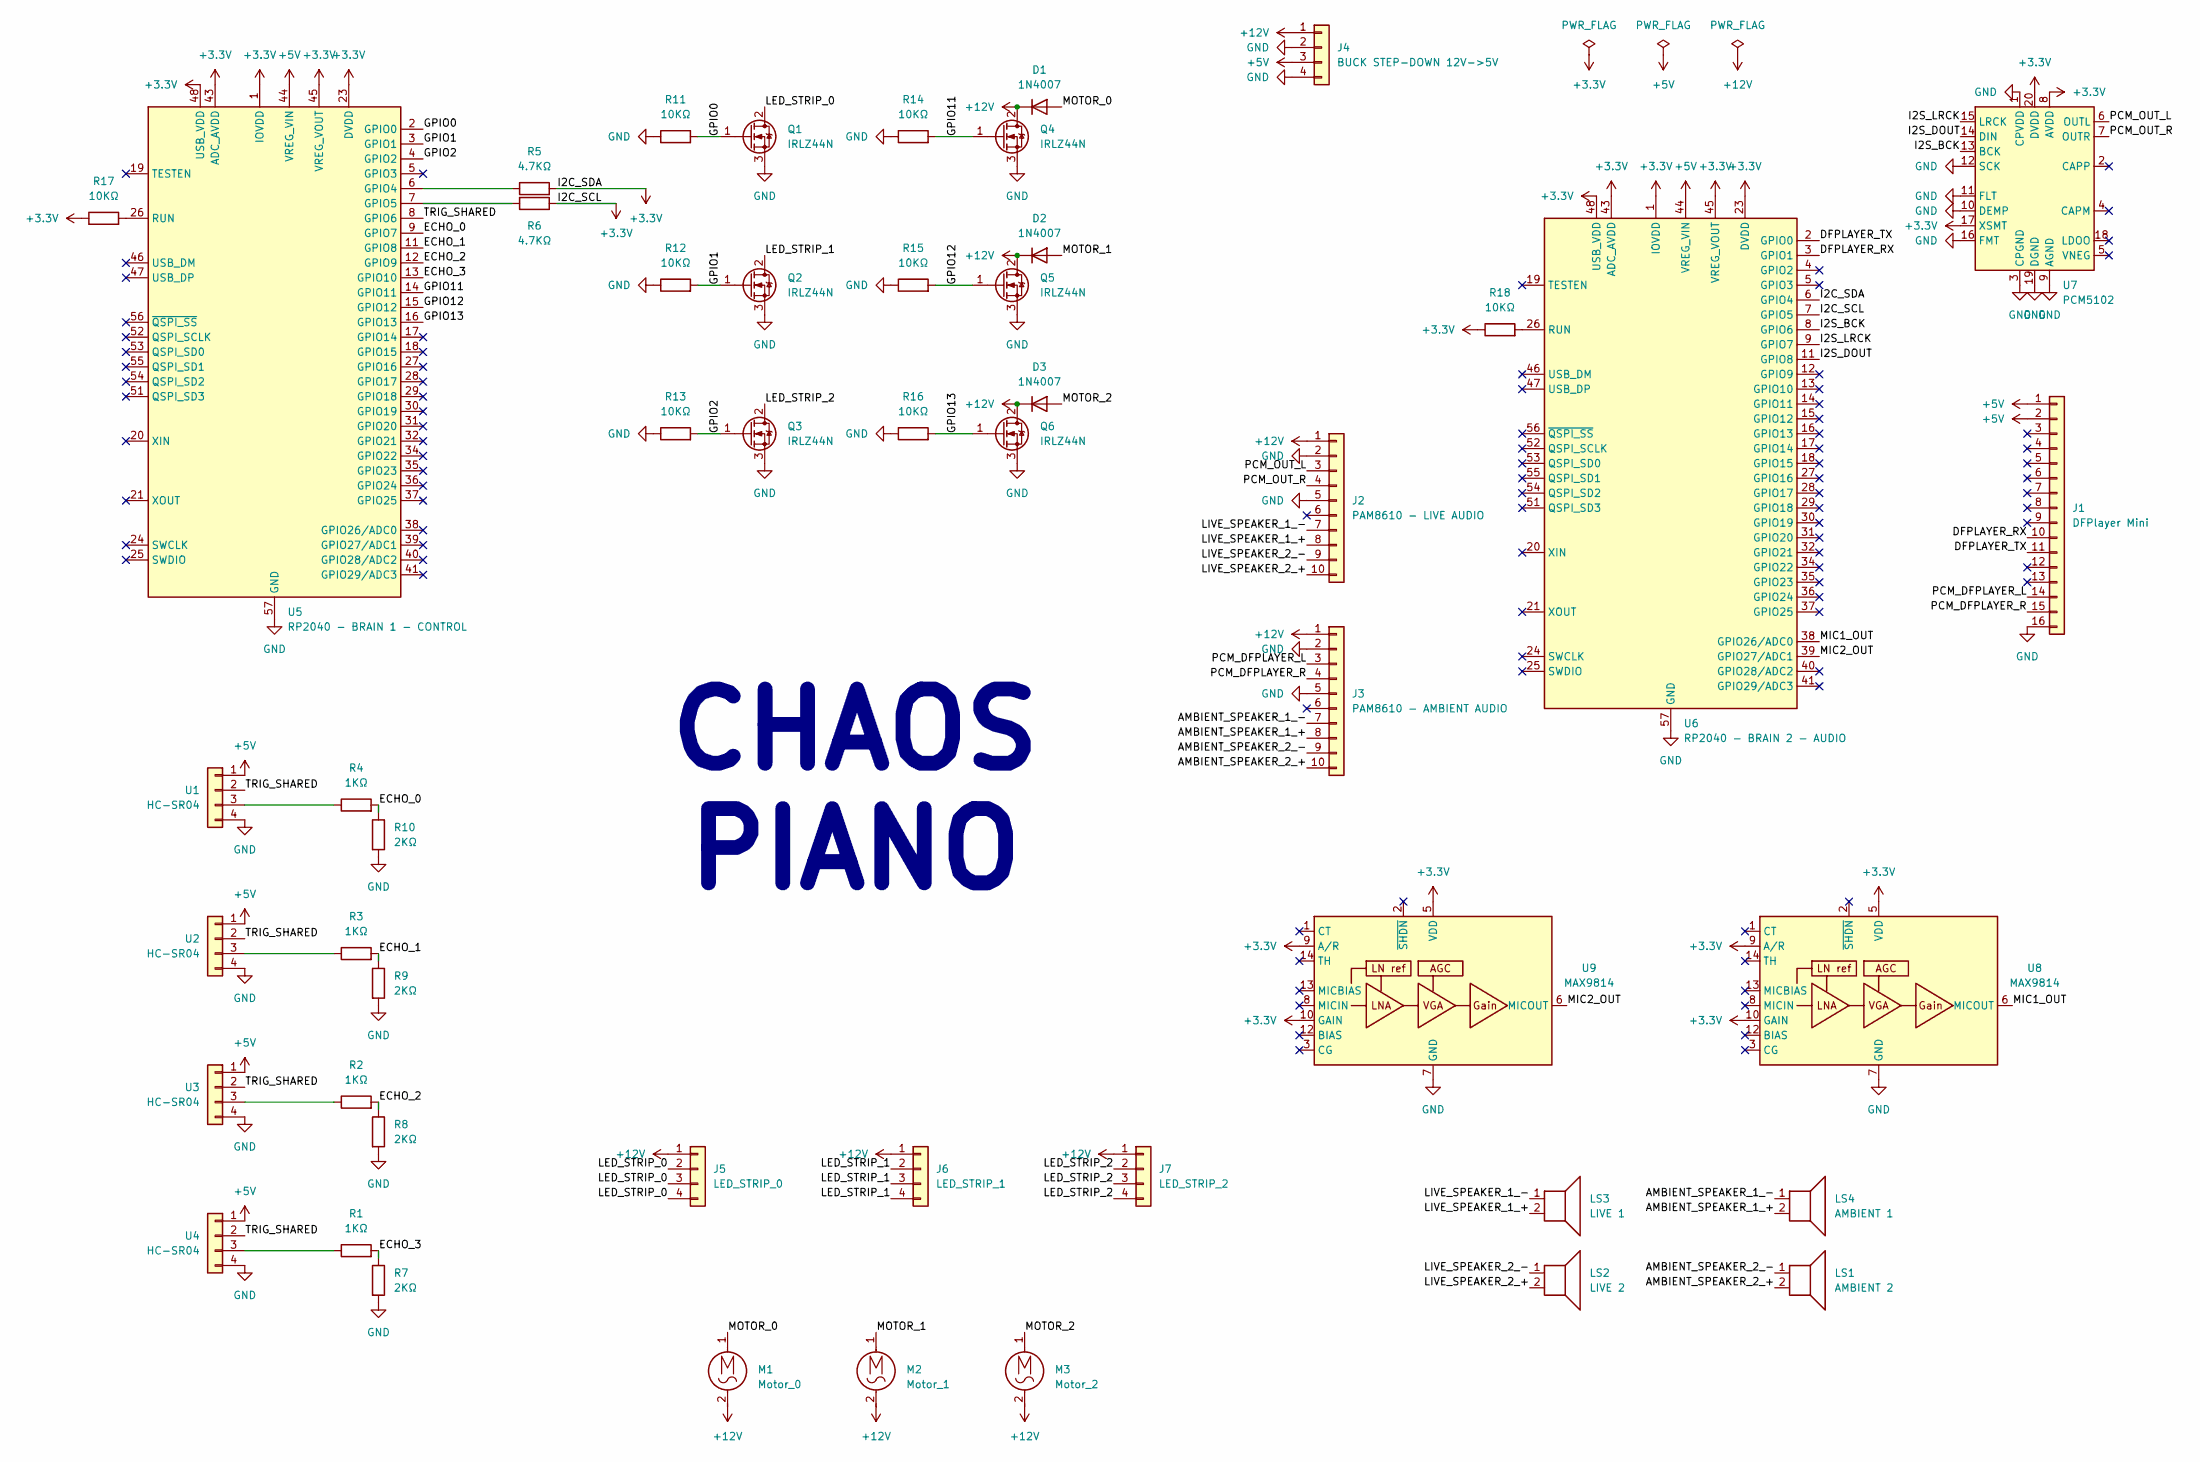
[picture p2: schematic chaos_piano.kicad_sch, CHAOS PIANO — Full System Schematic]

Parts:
D1, D2, D3: 1N4007; D_0201_0603Metric
J1: DFPlayer Mini; PinHeader_1x16_P2.54mm_Vertical
J2: PAM8610 - LIVE AUDIO; PinHeader_1x10_P2.54mm_Vertical
J3: PAM8610 - AMBIENT AUDIO; PinHeader_1x10_P2.54mm_Vertical
J4: BUCK STEP-DOWN 12V->5V; PinHeader_1x04_P2.54mm_Vertical
J5: LED_STRIP_0; PinHeader_1x04_P2.54mm_Vertical
J6: LED_STRIP_1; PinHeader_1x04_P2.54mm_Vertical
J7: LED_STRIP_2; PinHeader_1x04_P2.54mm_Vertical
LS1: AMBIENT 2; PinHeader_1x02_P2.54mm_Vertical
LS2: LIVE 2; PinHeader_1x02_P2.54mm_Vertical
LS3: LIVE 1; PinHeader_1x02_P2.54mm_Vertical
LS4: AMBIENT 1; PinHeader_1x02_P2.54mm_Vertical
M1: Motor_0; PinHeader_1x02_P2.54mm_Vertical
M2: Motor_1; PinHeader_1x02_P2.54mm_Vertical
M3: Motor_2; PinHeader_1x02_P2.54mm_Vertical
Q1, Q2, Q3, Q4, Q5, Q6: IRLZ44N; TO-220-3_Vertical
R1, R2, R3, R4: 1KΩ; R_0805_2012Metric
R5, R6: 4.7KΩ; R_0805_2012Metric
R7, R8, R9, R10: 2KΩ; R_0805_2012Metric
R11, R12, R13, R14, R15, R16, R17, R18: 10KΩ; R_0805_2012Metric
U1, U2, U3, U4: HC-SR04; PinHeader_1x04_P2.54mm_Vertical
U5: RP2040 - BRAIN 1 - CONTROL; QFN-56-1EP_7x7mm_P0.4mm_EP3.2x3.2mm
U6: RP2040 - BRAIN 2 - AUDIO; QFN-56-1EP_7x7mm_P0.4mm_EP3.2x3.2mm
U7: PCM5102; TSSOP-20_4.4x6.5mm_P0.65mm
U8, U9: MAX9814; DFN-14-1EP_3x3mm_P0.4mm_EP1.78x2.35mm

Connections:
+3.3V: R5.2, R6.1, R17.1, R18.1, U5.1 (IOVDD), U5.10 (IOVDD), U5.22 (IOVDD), U5.23 (DVDD), U5.33 (IOVDD), U5.42 (IOVDD), U5.43 (ADC_AVDD), U5.45 (VREG_VOUT), U5.48 (USB_VDD), U5.49 (IOVDD), U5.50 (DVDD), U6.1 (IOVDD), U6.6 (GPIO4), U6.7 (GPIO5), U6.10 (IOVDD), U6.22 (IOVDD), U6.23 (DVDD), U6.33 (IOVDD), U6.42 (IOVDD), U6.43 (ADC_AVDD), U6.45 (VREG_VOUT), U6.48 (USB_VDD), U6.49 (IOVDD), U6.50 (DVDD), U7.8 (AVDD), U7.17 (XSMT), U7.20 (DVDD), U8.5 (VDD), U8.9 (A/R), U8.10 (GAIN), U9.5 (VDD), U9.9 (A/R), U9.10 (GAIN)
+5V: J1.1, J1.2, J4.3, U1.1, U2.1, U3.1, U4.1, U5.44 (VREG_VIN), U6.44 (VREG_VIN)
+12V: D1.1 (K), D2.1 (K), D3.1 (K), J2.1, J3.1, J4.1, J5.1, J6.1, J7.1, M1.2, M2.2, M3.2, Q4.2 (D), Q5.2 (D), Q6.2 (D)
/AMBIENT_SPEAKER_1_+: J3.8, LS4.2
/AMBIENT_SPEAKER_1_-: J3.7, LS4.1
/AMBIENT_SPEAKER_2_+: J3.10, LS1.2
/AMBIENT_SPEAKER_2_-: J3.9, LS1.1
/DFPLAYER_RX: J1.10, U6.3 (GPIO1)
/DFPLAYER_TX: J1.11, U6.2 (GPIO0)
/ECHO_0: R4.2, R10.1, U5.9 (GPIO7)
/ECHO_1: R3.2, R9.1, U5.11 (GPIO8)
/ECHO_2: R2.2, R8.1, U5.12 (GPIO9)
/ECHO_3: R1.2, R7.1, U5.13 (GPIO10)
/GPIO0: Q1.1 (G), R11.2, U5.2 (GPIO0)
/GPIO1: Q2.1 (G), R12.2, U5.3 (GPIO1)
/GPIO2: Q3.1 (G), R13.2, U5.4 (GPIO2)
/GPIO11: Q4.1 (G), R14.2, U5.14 (GPIO11)
/GPIO12: Q5.1 (G), R15.2, U5.15 (GPIO12)
/GPIO13: Q6.1 (G), R16.2, U5.16 (GPIO13)
/I2S_BCK: U6.8 (GPIO6), U7.13 (BCK)
/I2S_DOUT: U6.11 (GPIO8), U7.14 (DIN)
/I2S_LRCK: U6.9 (GPIO7), U7.15 (LRCK)
/LED_STRIP_0: J5.2, J5.3, J5.4, Q1.2 (D)
/LED_STRIP_1: J6.2, J6.3, J6.4, Q2.2 (D)
/LED_STRIP_2: J7.2, J7.3, J7.4, Q3.2 (D)
/LIVE_SPEAKER_1_+: J2.8, LS3.2
/LIVE_SPEAKER_1_-: J2.7, LS3.1
/LIVE_SPEAKER_2_+: J2.10, LS2.2
/LIVE_SPEAKER_2_-: J2.9, LS2.1
/MIC1_OUT: U6.38 (GPIO26/ADC0), U8.6 (MICOUT)
/MIC2_OUT: U6.39 (GPIO27/ADC1), U9.6 (MICOUT)
/MOTOR_0: D1.2 (A), M1.1
/MOTOR_1: D2.2 (A), M2.1
/MOTOR_2: D3.2 (A), M3.1
/PCM_DFPLAYER_L: J1.14, J3.3
/PCM_DFPLAYER_R: J1.15, J3.4
/PCM_OUT_L: J2.3, U7.6 (OUTL)
/PCM_OUT_R: J2.4, U7.7 (OUTR)
/TRIG_SHARED: U1.2, U2.2, U3.2, U4.2, U5.8 (GPIO6)
GND: J1.16, J2.2, J2.5, J3.2, J3.5, J4.2, J4.4, Q1.3 (S), Q2.3 (S), Q3.3 (S), Q4.3 (S), Q5.3 (S), Q6.3 (S), R7.2, R8.2, R9.2, R10.2, R11.1, R12.1, R13.1, R14.1, R15.1, R16.1, U1.4, U2.4, U3.4, U4.4, U5.57 (GND), U6.57 (GND), U7.1 (CPVDD), U7.3 (CPGND), U7.9 (AGND), U7.10 (DEMP), U7.11 (FLT), U7.12 (SCK), U7.16 (FMT), U7.19 (DGND), U8.4 (GND), U8.7 (GND), U8.11 (GND), U8.15 (GND), U9.4 (GND), U9.7 (GND), U9.11 (GND), U9.15 (GND)
unnamed: R4.1, U1.3
unnamed: R3.1, U2.3
unnamed: R2.1, U3.3
unnamed: R1.1, U4.3
unnamed: R5.1, U5.6 (GPIO4)
unnamed: R6.2, U5.7 (GPIO5)
unnamed: R17.2, U5.26 (RUN)
unnamed: R18.2, U6.26 (RUN)

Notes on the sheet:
CHAOS PIANO

Board: 2 copper layers, 50 parts (0 on the bottom side), 48 nets, no tracks yet.

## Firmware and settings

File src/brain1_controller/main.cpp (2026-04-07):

// ===========================================================================
// Chaos Piano — Brain 1: Physical Controller
// ===========================================================================
//
// This is the "physical world" brain. It reads ultrasonic distance sensors,
// converts the closest detected distance into a 0-255 proximity byte, and
// sends it to Brain 2 (audio engine) over I2C. It also directly controls
// the vibrating motors and LED strip strobes via MOSFET-switched 12V PWM.
//
// DUAL-CORE ARCHITECTURE:
//   Core 0 — Sensor sweep (blocking pulseIn calls) + I2C transmission
//   Core 1 — LED strobe + motor PWM (independent timing, never blocked)
//
// The RP2040 has two independent ARM Cortex-M0+ cores. The arduino-pico
// framework lets you use both by defining setup1()/loop1() alongside the
// normal setup()/loop(). Both cores share RAM (including currentProximity),
// but execute independently.
//
// Core 1 runs the strobe because Core 0's sensor sweep blocks for up to
// ~300ms per cycle (pulseIn waits for each ultrasonic echo). If the strobe
// ran on Core 0, it would freeze during sensor reads.
// ===========================================================================

#include <Arduino.h>             // Core Arduino: pinMode, analogWrite, millis, etc.
#include <Wire.h>                // I2C library for communication with Brain 2
#include <Adafruit_NeoPixel.h>   // Onboard WS2812 RGB LED on GPIO16
#include "chaos_protocol.h"      // Shared constants: pins, I2C address, message format

// ===========================================================================
// TUNING PARAMETERS — adjust these during exhibit setup
// ===========================================================================

// --- Detection Range ---
constexpr uint16_t DETECT_MIN_CM = 1;       // Minimum detection distance (cm)
constexpr uint16_t DETECT_MAX_CM = 75;      // Maximum detection distance (cm)

// --- Motors ---
// Baseline: soft constant vibration that scales with proximity.
// Outbursts: random bursts to higher intensity, one motor at a time.
constexpr uint8_t MOTOR_BASELINE_MIN = 0;       // Baseline PWM at prox=0 (off when nobody near)
constexpr uint8_t MOTOR_BASELINE_MAX = 40;      // Baseline PWM at max proximity (gentle hum)
constexpr uint8_t MOTOR_BURST_MIN = 80;         // Minimum burst intensity
constexpr uint8_t MOTOR_BURST_MAX = 180;        // Maximum burst intensity (255 = full 12V)
constexpr uint16_t MOTOR_BURST_DUR_MIN = 50;    // Shortest burst duration (ms)
constexpr uint16_t MOTOR_BURST_DUR_MAX = 400;   // Longest burst duration (ms)
constexpr uint16_t MOTOR_PAUSE_MIN = 200;       // Shortest gap between bursts (ms)
constexpr uint16_t MOTOR_PAUSE_MAX = 2000;      // Longest gap between bursts (ms)
constexpr uint8_t MOTOR_FADE_SPEED = 8;         // PWM change per loop iteration during fade
                                                 // Higher = faster fade. At ~10kHz loop rate,
                                                 // 8 means full 0-255 ramp in ~3ms (sharp).
                                                 // 2 would be ~12ms (softer).

// --- LED Strobe ---
// IDLE mode: slow dim pulse when nobody is nearby (installation looks alive).
// ACTIVE mode: speed and brightness increase with proximity until full strobe.
// DROPOUTS: each LED independently goes dark for a random duration, then returns.
constexpr uint8_t LED_IDLE_BRIGHT = 15;          // Idle ON brightness (0-255)
constexpr uint8_t LED_IDLE_DIM = 5;              // Idle OFF brightness (0 = fully off)
constexpr uint16_t LED_IDLE_PERIOD_MS = 1000;    // Idle half-period in ms (1000 = 0.5Hz)
constexpr uint8_t LED_STROBE_BRIGHT_MIN = 30;    // Active brightness at low proximity
constexpr uint8_t LED_STROBE_BRIGHT_MAX = 255;   // Active brightness at max proximity
constexpr uint32_t LED_STROBE_SLOW_US = 500000;  // Slowest strobe half-period (µs) = 1Hz
constexpr uint32_t LED_STROBE_FAST_US = 2000;    // Fastest strobe half-period (µs) = 250Hz
constexpr uint8_t LED_PROX_THRESHOLD = 5;        // Below this proximity, LEDs go idle
constexpr uint16_t LED_DROPOUT_DUR_MIN = 30;     // Shortest dropout (ms)
constexpr uint16_t LED_DROPOUT_DUR_MAX = 100;    // Longest dropout (ms)
constexpr uint8_t LED_DROPOUT_CHANCE_MIN = 0;    // Dropout probability at low prox (0=never)
constexpr uint8_t LED_DROPOUT_CHANCE_MAX = 20;   // Dropout probability at max prox (out of 255)

// --- Sensor Filtering ---
constexpr uint8_t SENSOR_ZERO_MAX = 10;

// ===========================================================================
// END TUNING PARAMETERS
// ===========================================================================

// Onboard NeoPixel — blue heartbeat indicates Brain 1 is running.
Adafruit_NeoPixel pixel(1, PIN_NEOPIXEL, NEO_GRB + NEO_KHZ800);

// --- State variables ---
uint16_t sensorDistances[NUM_SENSORS] = {0};  // Current reading per sensor (cm)
volatile uint8_t currentProximity = 0;         // Shared between cores. 0=nobody, 255=close.
uint8_t validSensorCount = 0;                  // How many sensors got valid readings this sweep
uint32_t lastSweepTime = 0;                    // Timestamp of last sweep start

// ---------------------------------------------------------------------------
// Fast pseudo-random number generator (LCG)
// ---------------------------------------------------------------------------
// We need random numbers on Core 1 for the chaos effects. The standard
// random() function is not guaranteed to be thread-safe on the RP2040,
// so we use our own simple linear congruential generator. It's not
// cryptographically secure, but it's perfectly fine for visual/tactile
// randomness. The constants are the same ones used in glibc.
uint32_t chaosRNG = 42;  // Seed (any nonzero value works)

uint32_t chaosRandom() {
    chaosRNG = chaosRNG * 1664525 + 1013904223;
    return chaosRNG;
}

// Returns a random value in the range [min, max] inclusive.
uint16_t chaosRandomRange(uint16_t minVal, uint16_t maxVal) {
    if (minVal >= maxVal) return minVal;
    uint32_t range = maxVal - minVal + 1;
    return minVal + (uint16_t)(chaosRandom() % range);
}

// ---------------------------------------------------------------------------
// Ultrasonic Sensor Reading
// ---------------------------------------------------------------------------
uint16_t readSinglePing(uint8_t echoPin) {
    digitalWrite(PIN_US_TRIGGER, LOW);
    delayMicroseconds(2);
    digitalWrite(PIN_US_TRIGGER, HIGH);
    delayMicroseconds(10);
    digitalWrite(PIN_US_TRIGGER, LOW);

    uint32_t duration = pulseIn(echoPin, HIGH, US_TIMEOUT_US);
    if (duration == 0) return 0;

    uint16_t distanceCm = duration / 58;
    if (distanceCm > DETECT_MAX_CM) return 0;
    return distanceCm;
}

uint16_t median3(uint16_t a, uint16_t b, uint16_t c) {
    if (a > b) { uint16_t t = a; a = b; b = t; }
    if (b > c) { uint16_t t = b; b = c; c = t; }
    if (a > b) { uint16_t t = a; a = b; b = t; }
    return b;
}

uint16_t readSensorCm(uint8_t echoPin) {
    uint16_t r1 = readSinglePing(echoPin);
    delayMicroseconds(200);
    uint16_t r2 = readSinglePing(echoPin);
    delayMicroseconds(200);
    uint16_t r3 = readSinglePing(echoPin);
    return median3(r1, r2, r3);
}

// ---------------------------------------------------------------------------
// Sensor Sweep with timeout-based release
// ---------------------------------------------------------------------------
uint16_t lastValidDistance[NUM_SENSORS] = {0};
uint8_t zeroCount[NUM_SENSORS] = {0};

void sweepSensors() {
    uint16_t minDistance = DETECT_MAX_CM;
    validSensorCount = 0;

    for (uint8_t i = 0; i < NUM_SENSORS; i++) {
        uint16_t reading = readSensorCm(ECHO_PINS[i]);

        if (reading > 0) {
            sensorDistances[i] = reading;
            lastValidDistance[i] = reading;
            zeroCount[i] = 0;
        } else {
            zeroCount[i]++;
            if (zeroCount[i] >= SENSOR_ZERO_MAX) {
                lastValidDistance[i] = 0;
                sensorDistances[i] = 0;
            } else {
                sensorDistances[i] = lastValidDistance[i];
            }
        }

        if (sensorDistances[i] > 0) {
            validSensorCount++;
            if (sensorDistances[i] < minDistance) {
                minDistance = sensorDistances[i];
            }
        }
    }

    if (validSensorCount == 0) {
        currentProximity = 0;
    } else {
        currentProximity = (uint8_t)map(
            constrain(minDistance, DETECT_MIN_CM, DETECT_MAX_CM),
            DETECT_MIN_CM, DETECT_MAX_CM,
            255, 1
        );
    }
}

// ---------------------------------------------------------------------------
// I2C Transmission to Brain 2
// ---------------------------------------------------------------------------
void sendProximityToBrain2() {
    ProximityMessage msg;
    msg.header = MSG_HEADER_MAGIC;
    msg.proximity = currentProximity;
    msg.sensor_count = validSensorCount;
    msg.checksum = computeChecksum(msg.header, msg.proximity, msg.sensor_count);

    Wire.beginTransmission(I2C_TARGET_ADDRESS);
    Wire.write((uint8_t*)&msg, sizeof(msg));
    uint8_t error = Wire.endTransmission();
    if (error != 0) {
        Serial.print("I2C error: ");
        Serial.println(error);
    }
}

// ---------------------------------------------------------------------------
// Core 1: Chaotic LED Strobe + Motor Outbursts
// ---------------------------------------------------------------------------

// --- Motor outburst state (one per motor) ---
struct MotorState {
    uint8_t currentPWM;      // What we're actually outputting right now
    uint8_t targetPWM;       // What we're fading toward
    uint32_t burstEndTime;   // When the current burst expires (millis)
    uint32_t nextBurstTime;  // Earliest time the next burst can start (millis)
    bool bursting;           // Is this motor currently in a burst?
    bool useFade;            // Does this burst fade in/out or snap?
};

MotorState motors[NUM_MOTORS];

// --- LED dropout state (one per LED strip) ---
struct LEDDropoutState {
    uint32_t dropoutEndTime;   // When this LED comes back from dropout (millis)
    bool droppedOut;           // Is this LED currently blacked out?
};

LEDDropoutState ledDropouts[NUM_LEDS];

// Core 1 setup
void setup1() {
    for (uint8_t i = 0; i < NUM_LEDS; i++) {
        pinMode(LED_PINS[i], OUTPUT);
        digitalWrite(LED_PINS[i], LOW);
        ledDropouts[i].droppedOut = false;
        ledDropouts[i].dropoutEndTime = 0;
    }
    for (uint8_t i = 0; i < NUM_MOTORS; i++) {
        pinMode(MOTOR_PINS[i], OUTPUT);
        analogWrite(MOTOR_PINS[i], 0);
        motors[i].currentPWM = 0;
        motors[i].targetPWM = 0;
        motors[i].burstEndTime = 0;
        motors[i].nextBurstTime = 0;
        motors[i].bursting = false;
        motors[i].useFade = false;
    }

    // Seed the RNG with something that varies between boots.
    // micros() at the point Core 1 starts will differ slightly each time
    // due to USB enumeration timing, giving us a different sequence.
    chaosRNG = micros() ^ 0xDEADBEEF;
}

// Core 1 main loop
void loop1() {
    uint8_t prox = currentProximity;
    uint32_t now = millis();

    // =====================================================================
    // MOTORS: baseline hum + independent random outbursts
    // =====================================================================
    // Baseline PWM scales linearly with proximity.
    uint8_t baseline = MOTOR_BASELINE_MIN +
        ((uint16_t)prox * (MOTOR_BASELINE_MAX - MOTOR_BASELINE_MIN) / 255);

    // Check if any motor is currently bursting (we enforce one-at-a-time).
    bool anyBursting = false;
    for (uint8_t i = 0; i < NUM_MOTORS; i++) {
        if (motors[i].bursting) {
            anyBursting = true;
            break;
        }
    }

    for (uint8_t i = 0; i < NUM_MOTORS; i++) {
        MotorState& m = motors[i];

        if (m.bursting) {
            // --- Currently in a burst ---
            if (now >= m.burstEndTime) {
                // Burst is over: set target back to baseline
                m.bursting = false;
                m.targetPWM = baseline;
                // Schedule the next possible burst for this motor.
                // The pause duration shrinks with proximity: close = more frequent.
                uint16_t pauseRange = MOTOR_PAUSE_MAX - MOTOR_PAUSE_MIN;
                uint16_t pause = MOTOR_PAUSE_MAX -
                    (uint16_t)((uint32_t)prox * pauseRange / 255);
                m.nextBurstTime = now + chaosRandomRange(pause / 2, pause);
            }
        } else if (prox > 0 && !anyBursting && now >= m.nextBurstTime) {
            // --- Eligible for a new burst ---
            // Not all motors get picked every cycle. We roll the dice
            // to choose one randomly. This creates organic timing.
            // Higher proximity = higher chance of triggering.
            uint8_t roll = (uint8_t)(chaosRandom() >> 24);
            uint8_t chance = (uint8_t)((uint32_t)prox * 30 / 255);  // 0-30 out of 255
            if (roll < chance) {
                m.bursting = true;
                anyBursting = true;

                // Random burst intensity, biased higher at close proximity
                uint8_t burstIntensity = MOTOR_BURST_MIN +
                    (uint8_t)((uint32_t)prox * (MOTOR_BURST_MAX - MOTOR_BURST_MIN) / 255);
                // Add some randomness to the intensity (jitter +-20%)
                int16_t jitter = (int16_t)chaosRandomRange(0, burstIntensity / 5) -
                                 (int16_t)(burstIntensity / 10);
                burstIntensity = (uint8_t)constrain(
                    (int16_t)burstIntensity + jitter, MOTOR_BURST_MIN, 255);
                m.targetPWM = burstIntensity;

                // Random burst duration: shorter at low prox, longer at high prox
                uint16_t durRange = MOTOR_BURST_DUR_MAX - MOTOR_BURST_DUR_MIN;
                uint16_t dur = MOTOR_BURST_DUR_MIN +
                    (uint16_t)((uint32_t)prox * durRange / 255);
                // Add randomness to duration too
                m.burstEndTime = now + chaosRandomRange(dur / 2, dur);

                // Randomly choose fade or sharp attack (50/50)
                m.useFade = (chaosRandom() & 1) == 0;
            }
        }

        // If not bursting, target is always the baseline
        if (!m.bursting) {
            m.targetPWM = baseline;
        }

        // --- Apply fade or snap toward target ---
        if (m.useFade || !m.bursting) {
            // Fade: move currentPWM toward targetPWM by MOTOR_FADE_SPEED per iteration.
            // We always fade back DOWN to baseline (smooth return).
            // We randomly fade or snap UP to burst target (decided above).
            if (m.currentPWM < m.targetPWM) {
                uint16_t next = (uint16_t)m.currentPWM + MOTOR_FADE_SPEED;
                m.currentPWM = (next > m.targetPWM) ? m.targetPWM : (uint8_t)next;
            } else if (m.currentPWM > m.targetPWM) {
                int16_t next = (int16_t)m.currentPWM - MOTOR_FADE_SPEED;
                m.currentPWM = (next < m.targetPWM) ? m.targetPWM : (uint8_t)next;
            }
        } else {
            // Sharp: jump immediately to target
            m.currentPWM = m.targetPWM;
        }

        analogWrite(MOTOR_PINS[i], m.currentPWM);
    }

    // =====================================================================
    // LEDs: unified strobe with independent random dropouts
    // =====================================================================
    // The base strobe logic is the same as before (all LEDs share the same
    // toggle timer and rate). On top of that, each LED independently
    // decides to "drop out" (go dark) for a random duration.

    static uint32_t lastToggle = 0;
    static bool ledState = false;

    // Compute what brightness the strobe wants this cycle
    uint8_t strobeBrightness = 0;

    if (prox < LED_PROX_THRESHOLD) {
        // IDLE: slow dim pulse
        uint32_t nowMs = millis();
        if (nowMs - lastToggle >= LED_IDLE_PERIOD_MS) {
            lastToggle = nowMs;
            ledState = !ledState;
        }
        strobeBrightness = ledState ? LED_IDLE_BRIGHT : LED_IDLE_DIM;
    } else {
        // ACTIVE STROBE: speed and brightness scale with proximity
        uint32_t halfPeriodUs = map(prox, LED_PROX_THRESHOLD, 255,
                                    LED_STROBE_SLOW_US, LED_STROBE_FAST_US);
        uint8_t brightness = map(prox, LED_PROX_THRESHOLD, 255,
                                 LED_STROBE_BRIGHT_MIN, LED_STROBE_BRIGHT_MAX);
        uint32_t nowUs = micros();
        if (nowUs - lastToggle >= halfPeriodUs) {
            lastToggle = nowUs;
            ledState = !ledState;
        }
        strobeBrightness = ledState ? brightness : 0;
    }

    // Apply per-LED dropout logic on top of the shared strobe
    for (uint8_t i = 0; i < NUM_LEDS; i++) {
        LEDDropoutState& d = ledDropouts[i];

        if (d.droppedOut) {
            // Currently in a dropout: stay dark until time expires
            if (now >= d.dropoutEndTime) {
                d.droppedOut = false;
            }
        } else if (prox >= LED_PROX_THRESHOLD) {
            // Not dropped out: roll the dice each strobe ON edge to maybe start one.
            // We only check on the ON phase to avoid triggering during dark phases,
            // which would be invisible and waste the dropout.
            if (ledState) {
                uint8_t roll = (uint8_t)(chaosRandom() >> 24);
                uint8_t chance = LED_DROPOUT_CHANCE_MIN +
                    ((uint16_t)prox * (LED_DROPOUT_CHANCE_MAX - LED_DROPOUT_CHANCE_MIN) / 255);
                if (roll < chance) {
                    d.droppedOut = true;
                    d.dropoutEndTime = now +
                        chaosRandomRange(LED_DROPOUT_DUR_MIN, LED_DROPOUT_DUR_MAX);
                }
            }
        }

        // Output: if dropped out, force dark. Otherwise, use strobe brightness.
        analogWrite(LED_PINS[i], d.droppedOut ? 0 : strobeBrightness);
    }

    // Yield bus time to Core 0
    delayMicroseconds(100);
}

// ---------------------------------------------------------------------------
// Setup (Core 0)
// ---------------------------------------------------------------------------
void setup() {
    pixel.begin();
    pixel.setBrightness(30);
    pixel.setPixelColor(0, pixel.Color(0, 0, 255));
    pixel.show();

    Serial.begin(115200);
    delay(2000);

    Serial.println("=== Chaos Piano: Brain 1 (Physical Controller) ===");
    Serial.println("Core 0: Sensors + I2C | Core 1: LED strobe + Motors");
    Serial.print("Detection: ");
    Serial.print(DETECT_MIN_CM);
    Serial.print("-");
    Serial.print(DETECT_MAX_CM);
    Serial.println("cm");
    Serial.print("Motor baseline: ");
    Serial.print(MOTOR_BASELINE_MIN);
    Serial.print("-");
    Serial.print(MOTOR_BASELINE_MAX);
    Serial.print(" | Burst: ");
    Serial.print(MOTOR_BURST_MIN);
    Serial.print("-");
    Serial.println(MOTOR_BURST_MAX);
    Serial.print("Strobe: ");
    Serial.print(LED_STROBE_SLOW_US);
    Serial.print("-");
    Serial.print(LED_STROBE_FAST_US);
    Serial.println("us");
    Serial.print("LED dropout chance: ");
    Serial.print(LED_DROPOUT_CHANCE_MIN);
    Serial.print("-");
    Serial.println(LED_DROPOUT_CHANCE_MAX);

    pinMode(PIN_US_TRIGGER, OUTPUT);
    digitalWrite(PIN_US_TRIGGER, LOW);
    for (uint8_t i = 0; i < NUM_SENSORS; i++) {
        pinMode(ECHO_PINS[i], INPUT);
    }

    Wire.setSDA(PIN_I2C_SDA);
    Wire.setSCL(PIN_I2C_SCL);
    Wire.setClock(I2C_CLOCK_HZ);
    Wire.begin();

    Serial.println("Brain 1 ready. Proximity: 0=nobody, 255=close.");
}

// ---------------------------------------------------------------------------
// Main Loop (Core 0) — sensor sweep at 20Hz
// ---------------------------------------------------------------------------
void loop() {
    uint32_t now = millis();

    bool neoOn = ((now / 1000) % 2) == 0;
    pixel.setPixelColor(0, neoOn ? pixel.Color(0, 0, 255) : pixel.Color(0, 0, 0));
    pixel.show();

    if (now - lastSweepTime >= SENSOR_SWEEP_MS) {
        lastSweepTime = now;
        sweepSensors();
        sendProximityToBrain2();

        Serial.print("Prox: ");
        Serial.print(currentProximity);
        Serial.print(" | Sensors: ");
        Serial.print(validSensorCount);
        Serial.print(" | Distances: ");
        for (uint8_t i = 0; i < NUM_SENSORS; i++) {
            Serial.print(sensorDistances[i]);
            Serial.print("cm ");
        }
        Serial.println();
    }
}

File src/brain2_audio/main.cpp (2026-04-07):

// ===========================================================================
// Chaos Piano — Brain 2: Full Audio Engine
// ===========================================================================
//
// This is the "audio world" brain. It receives proximity data from Brain 1
// over I2C and uses it to control a real-time audio processing pipeline.
// Two parallel signal paths are mixed at the output:
//
//   DRONE PATH (synthesized):
//     Sine oscillator → Distortion → Bitcrusher → Flanger → Volume → Autopan
//     All effects scale with proximity: 0=clean sine, 255=full chaos.
//
//   MIC PATH (live input from MAX9814 condenser mic):
//     ADC (DMA) → Noise Gate → Volume → Reverb → Delay
//     Reverb/delay add space to live sounds; gate prevents feedback.
//
//   FINAL MIX:
//     Drone (stereo, panned) + Mic (mono, centered) → I2S → PCM5102 DAC → speakers
//
//   DFPLAYER (separate analog path):
//     Brain 2 sends UART volume commands → DFPlayer → its own DAC → PAM8610 #2
//     This is an ambient track that plays continuously alongside the live audio.
//
// ===========================================================================

#include <Arduino.h>             // Core Arduino functions
#include <ADCInput.h>            // DMA-based ADC for jitter-free mic sampling
#include <Wire.h>                // I2C library (target/slave mode)
#include <I2S.h>                 // I2S output to PCM5102 DAC
#include <Adafruit_NeoPixel.h>   // Onboard WS2812 LED on GPIO16
#include "chaos_protocol.h"      // Shared constants: pins, I2C address, message format

// ===========================================================================
// TUNING PARAMETERS — adjust these during exhibit setup
// ===========================================================================

// --- Mic Input ---
constexpr int16_t MIC_BIAS = 1540;          // DC offset of MAX9814 output (measured, not 2048)
constexpr uint8_t MIC_VOLUME = 75;       // Mic loudness: 0=silent, 128=unity, 255=2x boost

// --- Noise Gate (mic) ---
// The gate prevents the mic from amplifying room noise and speaker feedback
// when nobody is making sounds. It uses an asymmetric envelope follower:
// attack is fast (gate opens quickly when you clap) and release is slow
// (gate stays open briefly after sound stops, preserving natural decay).
constexpr float GATE_THRESHOLD = 1500.0f;   // Below this envelope level → mute mic
constexpr float GATE_ATTACK = 0.5f;         // Gate open speed (0.0-1.0, higher=faster)
constexpr float GATE_RELEASE = 0.1f;        // Gate close speed (lower=slower tail)

// --- Reverb (mic only) ---
// Schroeder reverb: 4 parallel comb filters with different delay lengths.
// Each comb filter recirculates the signal with decay, creating dense echoes.
constexpr uint8_t REVERB_DECAY = 215;       // Tail: 190≈2s, 210≈4s, 220≈6s. Stay below 225!
constexpr uint8_t REVERB_WET = 200;         // Wet/dry: 0=dry, 128=50/50, 255=all reverb

// --- Delay (mic only) ---
// Simple delay line: input is written to a circular buffer, output is read
// from DELAY_TIME_MS earlier. Feedback recirculates the delayed signal.
constexpr uint16_t DELAY_TIME_MS = 600;     // Echo time in ms (300-600 for rhythmic feel)
constexpr uint8_t DELAY_FEEDBACK = 100;     // Repeats: 0=one echo, 128=many, 200+=danger
constexpr uint8_t DELAY_MIX = 140;          // Echo volume: 0=dry, 128=equal to dry, 200=loud

// --- Drone Oscillator ---
constexpr uint16_t DRONE_FREQ_HZ = 440;     // Base frequency in Hz (440 = concert A)
constexpr uint8_t DRONE_PRE_SHIFT = 2;      // Right-shift before effects chain for headroom
                                             // 2=quarter amplitude, 3=eighth. Prevents clipping.
constexpr uint8_t DRONE_VOLUME_MIN = 0;     // Volume at prox 0 (0-255). 1 = barely audible.
constexpr uint8_t DRONE_VOLUME_MAX = 75;    // Volume at prox 255. Keep low so mic is audible.

// --- Distortion (drone only) ---
// Hard clipping with gain. The gain multiplier increases with proximity,
// pushing the waveform into clipping more aggressively.
constexpr uint8_t DIST_GAIN_MULTIPLIER = 7; // Max gain = 1 + (255 × this / 256). 7 = up to 8x.

// --- Bitcrusher (drone only) ---
// Reduces bit depth by right-shifting then left-shifting. At max proximity,
// up to BITCRUSH_MAX_BITS bits are lost, creating a gritty lo-fi sound.
constexpr uint8_t BITCRUSH_MAX_BITS = 12;   // Maximum bits crushed at prox 255 (12 = very harsh)

// --- Flanger (drone only) ---
// Reads from a delay buffer at a position modulated by a triangle-wave LFO.
// The moving delay creates a sweeping comb filter (the "jet engine" sound).
constexpr uint32_t FLANGER_LFO_SPEED = 97391;  // LFO phase increment per sample (~0.5Hz)
constexpr uint16_t FLANGER_BUF_SIZE = 1024;     // Delay buffer size in samples (power of 2!)

// --- Autopan (drone only) ---
// Triangle-wave LFO that moves the drone between left and right speakers.
// Speed and depth both increase with proximity (Leslie cabinet effect).
constexpr uint32_t PAN_SPEED_MIN = 15000;   // LFO speed when far (very slow drift)
constexpr uint32_t PAN_SPEED_MAX = 300000;  // LFO speed when close (moderate sweep)
constexpr uint8_t PAN_DEPTH_MIN = 0;        // Pan depth when far (0=dead center)
constexpr uint8_t PAN_DEPTH_MAX = 200;      // Pan depth when close (255=full hard LR)

// --- DFPlayer (ambient track) ---
constexpr uint8_t DFPLAYER_VOL_MIN = 10;     // Volume when nobody near (DFPlayer 0-30 range)
constexpr uint8_t DFPLAYER_VOL_MAX = 30;    // Volume at max proximity
constexpr uint16_t DFPLAYER_TRACK = 1;      // Track to loop (001.mp3 on SD card)

// --- Glitch / Broken Transmission (DFPlayer only) ---
// Random muting of the DFPlayer to simulate an unstable signal.
// Set GLITCH_CHANCE_MAX to 0 to disable entirely (no CPU cost when disabled).
constexpr uint8_t GLITCH_CHANCE_MIN = 0;    // Probability when far (0=never)
constexpr uint8_t GLITCH_CHANCE_MAX = 0;    // Probability when close (0=disabled, 120=frequent)
constexpr uint16_t GLITCH_MIN_LENGTH = 2000;  // Shortest cut in samples (2000 ≈ 45ms)
constexpr uint16_t GLITCH_MAX_LENGTH = 10000; // Longest cut in samples (10000 ≈ 227ms)
constexpr int16_t GLITCH_FADE_SPEED = 4;    // Gain change per sample during fade (higher=faster)

// ===========================================================================
// END TUNING PARAMETERS
// ===========================================================================

// Onboard NeoPixel — green triple-flash pattern indicates Brain 2.
Adafruit_NeoPixel pixel(1, PIN_NEOPIXEL, NEO_GRB + NEO_KHZ800);
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

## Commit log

2026-02-13 Repo initialization. Code, phase 1 doc and hardware schematics
    [Chaos_Piano_Phase1.kicad_sch]
2026-03-02 v0.2: Audio chain validation — DFPlayer + MAX9814 piezo + DSP effects
    [Chaos_Piano_V0.1.kicad_sch]
2026-04-07 Final desk prototype - dual PSU, dual mics, chaotic actuation
    [chaos_piano.kicad_pcb, chaos_piano.kicad_sch]
2026-04-07 Remove obsolete folder structure
    [Chaos_Piano_V0.1.kicad_sch]
